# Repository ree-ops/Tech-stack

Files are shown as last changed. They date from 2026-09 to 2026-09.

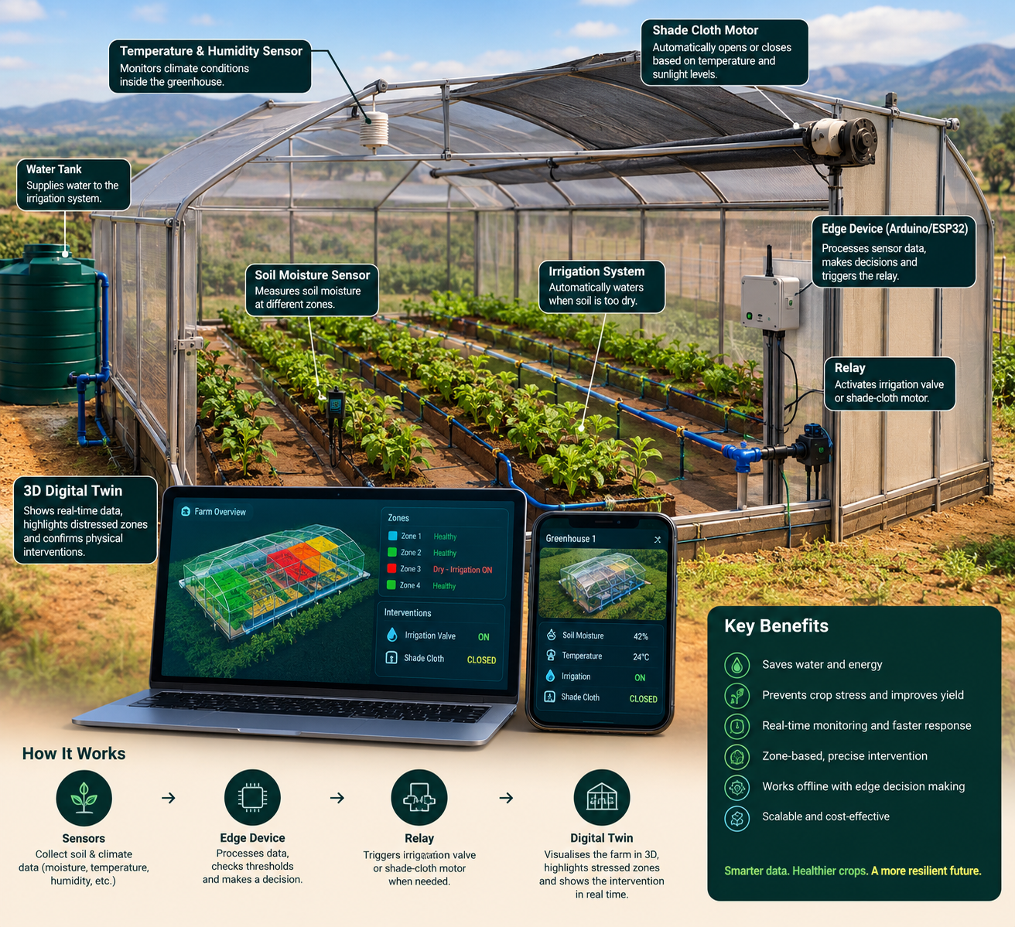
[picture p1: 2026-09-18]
EC861BFA-21BD-451A-801A-F8F32CB526BC.png

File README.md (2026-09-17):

# Lowveld Grove — Domain 2

MICTSETA Hackathon 2026, Domain 2: Smart Agribusiness & Climate Defence for
Macadamia/Citrus. A cyber-physical prototype that monitors soil moisture and
canopy temperature across several orchard sections, detects how fast each is
drying out or heating up, estimates hours until critical stress, and ranks
sections by which needs water first. When a section crosses threshold it
deploys a shade-cloth actuator and, if moisture keeps falling, switches on an
irrigation pump automatically — all shown live on a 3D digital twin. Full
detail: [docs/build-plan.md](docs/build-plan.md).

## Architecture

```
ESP32 edge node (src/edge)  --MQTT publish-->  MQTT broker
                                                    |
                                              MQTT subscribe
                                                    v
                                    mqtt-bridge (src/backend/mqtt-bridge)
                                                    |
                                          WebSocket / REST
                                          /                  \
                             dashboard (src/dashboard)   mobile (src/mobile)
                             React + Vite, 3D twin        Expo React Native
```

A simulator inside `mqtt-bridge` drives several zones with no hardware
attached — the identical dual-demo fallback path described in the build plan.
The real ESP32 rig (zone `04` / West block) can run alongside the simulated
zones, so the demo always has multiple sections to prioritize between even
with one physical rig.

`mqtt-bridge` enriches raw telemetry with a predictive layer before
broadcasting it: drying/warming rate, hours until critical stress, a
`stress_code` (`OK`/`WATCH`/`WARNING`/`CRITICAL`), and a `priority_rank`
across zones. See [src/backend/mqtt-bridge/README.md](src/backend/mqtt-bridge/README.md)
for the full zone status shape and the thresholds behind it.

```json
{
  "zone_id": "04",
  "label": "West block",
  "soil_moisture": 27.4,
  "canopy_temp": 29.1,
  "actuator_on": true,
  "pump_on": false,
  "moisture_rate_pct_per_hr": -3.2,
  "temp_rate_c_per_hr": 0.8,
  "hours_to_critical": 4.5,
  "stress_code": "WARNING",
  "priority_rank": 1,
  "ts": 1737024000000
}
```

## Repo layout

```
lowveld-grove/
  src/
    edge/                  # ESP32 firmware (Arduino, hand-written by the team)
    backend/mqtt-bridge/   # Node.js/TypeScript MQTT-to-WebSocket bridge + simulator
    dashboard/             # React (Vite) web app — 3D digital twin, chart, controls
    mobile/                # React Native (Expo) companion app
  cad/                     # optional enclosure/mounting designs
  slides/                  # pitch deck
  media/                   # team + build-progress photos
  docs/build-plan.md       # full build plan
```

## Setup

Requires Node.js 18+ and npm. Each project has its own `package.json`; there is
no shared workspace root, so `npm install` in each directory separately:

```bash
# 1. Backend (MQTT bridge + simulator)
cd src/backend/mqtt-bridge
cp .env.example .env
npm install
npm run dev            # http://localhost:8080, ws://localhost:8080/ws

# 2. Web dashboard
cd src/dashboard
cp .env.example .env
npm install
npm run dev            # http://localhost:5173

# 3. Mobile companion app
cd src/mobile
npm install
npx expo start
```

The bridge runs its own simulator by default (`SIMULATE_ON_BOOT=true`), so the
dashboard and mobile app work with no hardware attached. Once
`src/edge/farm_edge_node.ino` is flashed and publishing real MQTT data, set
`SIMULATE_ON_BOOT=false` in the bridge's `.env`.

## Demo script (the Dual-Demo)

1. **Virtual simulation** — open the dashboard, pick a section in the
   priority queue, click "Simulate heat stress" on it and watch it drift into
   stress: the stress code escalates OK → WATCH → WARNING → CRITICAL, "hours
   to critical" counts down, the shade cloth deploys and the pump switches on
   in the 3D twin, and it climbs to #1 in the priority queue. Click "Reset to
   healthy" to show recovery.
2. **Physical hardware** — show the wired ESP32/sensor/servo rig; dry the soil
   sample so the real servo moves on its own; with the simulator off, show the
   dashboard and mobile app updating that section from the real sensor.

Full script, wiring diagram, component list, and calibration steps:
[docs/build-plan.md](docs/build-plan.md).

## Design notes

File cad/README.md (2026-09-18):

# cad

3D-printable parts for the demo, written as OpenSCAD (`.scad`) source files
rather than pre-rendered STLs — free, text-based, and easy to tweak.

## Setup

1. Install [OpenSCAD](https://openscad.org/downloads.html) (free, macOS/Windows/Linux).
2. Open a `.scad` file below.
3. Press **F5** to preview, **F6** to fully render.
4. **File → Export → Export as STL**, then slice and print as usual.

These have not been test-printed — preview and check dimensions against your
actual hardware before committing filament to a print.

## Files

- **`electronics_enclosure.scad`** — a two-part project box (base + lid) for
  the Uno/ESP32 + breadboard rig, with cutouts for the USB cable and sensor
  wiring. **Measure your actual breadboard's length/width before printing**
  — the defaults at the top of the file are reasonable guesses for a
  standard full-size breadboard, not measurements of your specific setup.
  Boxing the wiring in also helps with the loose-connection issues we've
  been chasing during testing — less chance of a wire getting bumped.

- **`zone_marker_stake.scad`** — a small labeled ground stake for the demo
  table. Print 4 of these, changing `ZONE_LABEL` at the top of the file
  each time (`NORTH BLOCK`, `EAST BLOCK`, `SOUTH BLOCK`, `WEST BLOCK`) to
  match the dashboard's zone names — push one into each pot/soil tray so
  judges can see which physical section corresponds to which zone on
  screen.

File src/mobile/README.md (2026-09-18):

# mobile

Expo (React Native + TypeScript) companion app: a field-monitoring view of the
same live telemetry feed as the web dashboard, with the same "Simulate heat
stress" / "Reset to healthy" controls, priority queue, and weather widget
(temperature, humidity, rain forecast), for showing the demo from a phone.

## Setup

```bash
npm install
npm start
```

**Use `npm start` / `npm run android` / `npm run ios`, not `npx expo start`
directly** — those npm scripts auto-run `scripts/sync-lan-ip.js` first, which
detects this Mac's current WiFi IP and writes it into `app.json` for you.
Laptop IPs change often (DHCP renewals, switching networks), and a stale IP
in `app.json` is the single most common reason the app shows "CONNECTING"
forever on a physical phone. If you do run `npx expo start` directly for some
reason, run `npm run sync-lan-ip` first.

## Pointing at the backend

Phone and laptop must be on the same WiFi network as the `mqtt-bridge`
backend (`../backend/mqtt-bridge`) — the auto-sync script only fixes the IP
address in `app.json`, it can't get around the phone and laptop being on
genuinely different networks.

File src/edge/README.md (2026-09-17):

# edge

Two boards now, split by job:

- **`uno_sensor_node/`** (Arduino Uno, Arduino IDE / C++) — owns both sensors.
  Reads the soil moisture sensor and DHT22, sends raw readings to the ESP32
  over a serial link. No WiFi, no MQTT, no thresholds — just sensor reads.
- **`farm_edge_node.py`** (ESP32, **MicroPython, flashed and run via Thonny**)
  — receives those readings, converts the raw soil value to a moisture
  percentage, decides shade-cloth and irrigation-pump state locally, drives
  both, and publishes over MQTT to `lowveld-grove/zone04/telemetry` using the
  same schema the backend's simulator produces.

(The build plan in `docs/build-plan.md` describes a single-board Arduino IDE
path instead; this team split sensors onto a Uno and kept WiFi/MQTT/actuation
on the ESP32, which is why the setup below differs from that doc.)

```json
{
  "zone_id": "04",
  "soil_moisture": 27.4,
  "canopy_temp": 29.1,
  "actuator_on": true,
  "pump_on": false,
  "ts": 1737024000000
}
```

## Why two boards, and the one wiring rule that matters

The Uno's own header pins were simpler to wire the sensors into directly
than sharing breadboard rails across everything. The tradeoff: the two
boards now need a serial link between them, and their logic levels don't
match — the Uno runs 5V logic, the ESP32's pins are 3.3V-only and can be
damaged by 5V.

**Uno → ESP32 (the direction that needs protection):**
```
Uno D3 (TX) ──[1kΩ]──●──[2kΩ]──── GND
                      │
                ESP32 GPIO25 (RX)
```
That divider drops 5V to ~3.3V. Don't skip it.

**ESP32 → Uno (the safe direction, no divider needed):**
```
ESP32 GPIO26 (TX) ──────────────── Uno D2 (RX)
```
3.3V is still read as a clear HIGH by the Uno's 5V-logic input, so this one
just needs a direct wire.

**Plus a shared ground:**
```
ESP32 GND ──────────────────────── Uno GND
```

GPIO25/26 (not the more common 16/17) on purpose — those double as PSRAM
lines on WROVER-variant ESP32 boards, so 25/26 sidesteps that conflict
regardless of which variant you have.

## Setup — Uno (Arduino IDE)

1. Install the **DHT sensor library** (Adafruit) and **Adafruit Unified
   Sensor** via Library Manager.
2. Wire the soil sensor to A0 and the DHT22 to D4, both powered from the
   Uno's own 5V/GND pins — no breadboard rail-sharing needed, everything
   plugs straight into the Uno's header.
3. Wire the serial link and divider to the ESP32 as above.
4. Open `uno_sensor_node/uno_sensor_node.ino`, upload it, then open the
   Serial Monitor (9600 baud) to confirm it prints `-> ESP32: soil_raw=...
   temp=...` every 2 seconds. Note the raw value dry, then in a cup of
   water — you'll need both for calibration.

## Setup — ESP32 (Thonny)

1. Flash MicroPython onto the ESP32 if you haven't already (Thonny:
   **Tools → Options → Interpreter → Install or update firmware**), then
   confirm the bottom-right of Thonny shows `MicroPython (ESP32)` connected
   over USB serial.
2. Wire the servo signal to GPIO13 and the pump relay's signal pin to
   GPIO27 (the relay/MOSFET module switches the pump itself — a GPIO pin
   can't drive a pump's current directly).
3. Install the MQTT client library (needs WiFi connected first):

   ```python
   import network
   wlan = network.WLAN(network.STA_IF)
   wlan.active(True)
   wlan.connect("YOUR_SSID", "YOUR_PASSWORD")
   # wait until wlan.isconnected() is True, then:
   import mip
   mip.install("umqtt.simple")
   ```

   Or via Thonny's menu: **Tools → Manage Packages** → search
   `umqtt.simple` → install.
4. Open `farm_edge_node.py`, fill in `WIFI_SSID` / `WIFI_PASSWORD`, and set
   `SOIL_DRY_RAW` / `SOIL_WET_RAW` from the raw values you noted on the
   Uno's Serial Monitor in step 4 above. Check the threshold constants
   match the backend's `.env` (`src/backend/mqtt-bridge/.env.example`).
5. Save it onto the device as `main.py` (Thonny: **File → Save As...** →
   pick the MicroPython device → filename `main.py`) so it runs
   automatically on power-up for an untethered demo. Running it via the
   editor's ▶ button first (as `<untitled>` / any other filename) is fine
   for testing — it just won't survive a reboot until it's saved as
   `main.py`.

## Testing against the software stack

With both boards powered and wired together, and `src/backend/mqtt-bridge`
running (`npm run dev`), watch the Thonny Shell for `[MQTT] {...}` print
lines, then open the dashboard (`http://localhost:5173`) — zone `04` ("West
block") should switch from the backend's simulator to these real readings
automatically; the other three zones stay simulator-driven so the priority
queue still has multiple sections to compare.

If the ESP32 keeps printing "No (recent) data from Uno yet": check the Uno's
own Serial Monitor is still printing lines (confirms the Uno side is fine),
then check the divider and the TX/RX wires aren't swapped — the single most
common mistake here is connecting TX to TX instead of TX to RX.

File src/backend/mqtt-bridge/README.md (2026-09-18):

# mqtt-bridge

Subscribes to the farm telemetry MQTT topic and forwards zone status to the
dashboard (web) and mobile app over a shared WebSocket feed. Also runs a
fallback simulator across several zones so the dashboard works with no
hardware attached, and exposes the "Simulate heat stress event" / "Reset to
healthy" REST triggers used by both frontends.

On top of raw telemetry, every zone is run through a predictive layer
(`src/prediction.ts`) that:

- **detects drying/warming rate** — soil moisture %/hr and canopy temp °C/hr,
  from a rolling trend window (`TREND_WINDOW_MS`, default 10 min; needs at
  least 3 min of history before it trusts a slope, and ignores swings smaller
  than the sensor-noise deadband — see the comments in `prediction.ts`)
- **estimates hours until critical stress** (`hours_to_critical`) by
  projecting that rate forward to `CRITICAL_MOISTURE` / `CRITICAL_TEMP`
- **assigns a predictive stress code** — `OK` / `WATCH` / `WARNING` / `CRITICAL`
- **ranks zones by urgency** (`priority_rank`) — soonest-to-critical first,
  answering "which side needs water first"

The irrigation pump (`pump_on`) switches on automatically once soil moisture
drops to `PUMP_MOISTURE_THRESHOLD`, independently of the shade-cloth actuator
(`actuator_on`, driven by `MOISTURE_THRESHOLD` / `CRITICAL_TEMP`).

`src/weather.ts` polls OpenWeatherMap every `WEATHER_POLL_INTERVAL_MS` (needs
`OPENWEATHER_API_KEY` set) for the coordinates in `WEATHER_LAT`/`WEATHER_LON`,
and broadcasts it to clients. If rain is expected in the next ~9 hours,
simulated zones defer switching the pump on (no point irrigating right before
the sky does it for free) — the shade cloth still responds to heat/dryness
regardless. Real hardware zones aren't affected by this: they decide locally
on-device, per the no-cloud-dependency design; the weather check only
applies to the simulated fallback.

**Humidity feeds the "hours to critical" projection directly**, for every
zone (real or simulated) — this one *is* a backend analytics adjustment, not
an actuation decision, so it applies uniformly. Low ambient humidity means
faster evaporation than the sensor trend alone would suggest, so
`getHumidityDryingMultiplier()` in `weather.ts` scales the moisture-based
projection: >1 shortens the estimate (drying faster than the raw trend
implies), <1 lengthens it, with 50% humidity as the neutral baseline. It's a
simple, explainable multiplier, not a full evapotranspiration model — good
enough for "does this need water in the next hour or the next day," not
agronomic precision.

## Setup

```bash
cp .env.example .env
npm install
npm run dev
```

Server listens on `http://localhost:8080`, with the live feed at
`ws://localhost:8080/ws`.

## Endpoints

- `GET /api/zones` — every zone's current status, prediction, and priority rank
- `GET /api/weather` — latest weather snapshot (`{ weather: WeatherSnapshot | null }`)
- `POST /api/simulate/heat-stress` — `{ "zone_id": "03" }` drives that simulated zone into a stress event (omit `zone_id` to affect all simulated zones)
- `POST /api/simulate/reset` — same shape, returns a zone (or all) to healthy
- `ws://.../ws` — pushes `{ type: 'zones', payload: ZoneStatus[] }`, `{ type: 'event', payload }`, and `{ type: 'weather', payload: WeatherSnapshot }` messages

## Zone status shape

```json
{
  "zone_id": "04",
  "label": "West block",
  "soil_moisture": 27.4,
  "canopy_temp": 29.1,
  "actuator_on": true,
  "pump_on": false,
  "moisture_rate_pct_per_hr": -3.2,
  "temp_rate_c_per_hr": 0.8,
  "hours_to_critical": 4.5,
  "stress_code": "WARNING",
  "priority_rank": 1,
  "ts": 1737024000000
}
```

The MQTT wire schema from the ESP32 (`src/edge/farm_edge_node.ino`) only needs
`zone_id`, `soil_moisture`, `canopy_temp`, `actuator_on`, `ts` — `pump_on` is
optional on the wire and defaults from `PUMP_MOISTURE_THRESHOLD` if the
firmware doesn't send it yet. Everything else (`label`, the rate/prediction
fields, `priority_rank`) is computed by this bridge, not by the device.

Set `SIMULATE_ON_BOOT=false` in `.env` once the real ESP32 edge node is
publishing to the MQTT topic — its zone (`04` / West block by default, see
`src/zones.ts`) will then be driven by real sensor data while the rest stay
simulated, which is useful for a demo with only one physical rig.

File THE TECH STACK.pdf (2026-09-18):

# DOMAIN 2 : SMART AGRIBUSINESS &

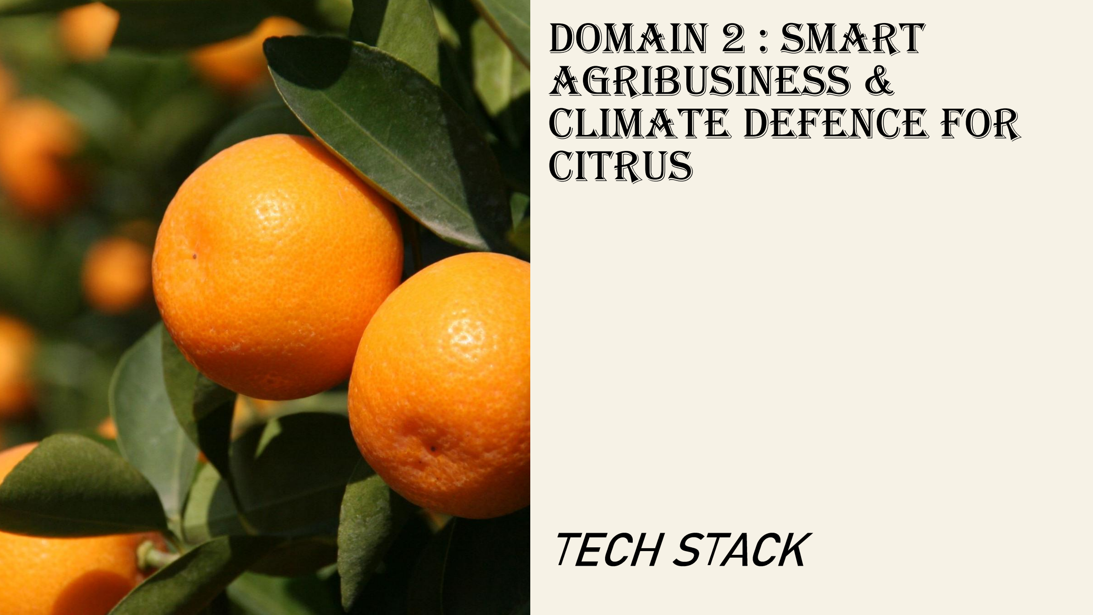
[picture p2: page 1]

# CLIMATE DEFENCE FOR CITRUS

# TECH STACK

# INTRODUCTION

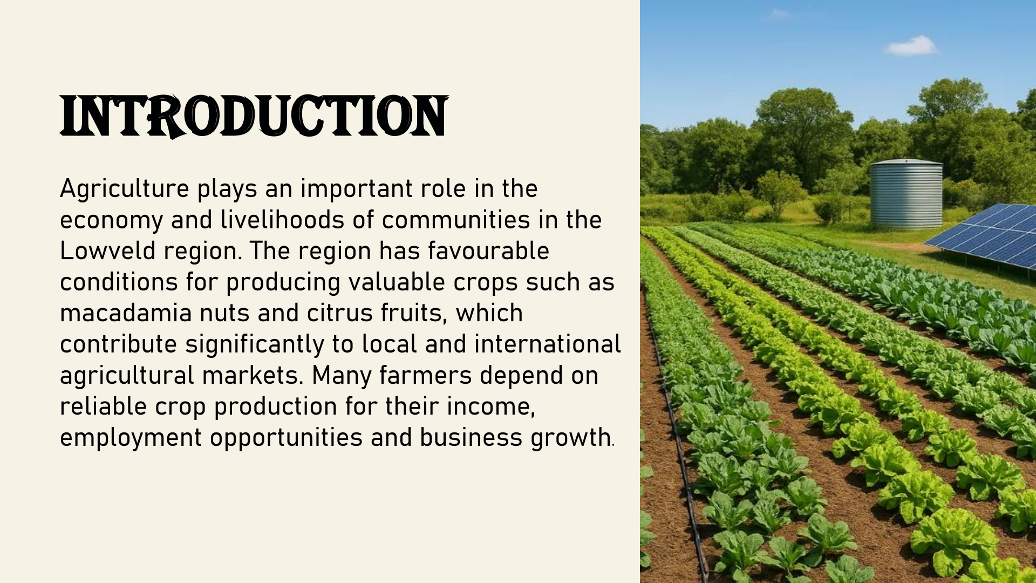
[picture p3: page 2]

Agriculture plays an important role in the economy and livelihoods of communities in the Lowveld region. The region has favourable conditions for producing valuable crops such as macadamia nuts and citrus fruits, which contribute significantly to local and international agricultural markets. Many farmers depend on

reliable crop production for their income, employment opportunities and business growth .

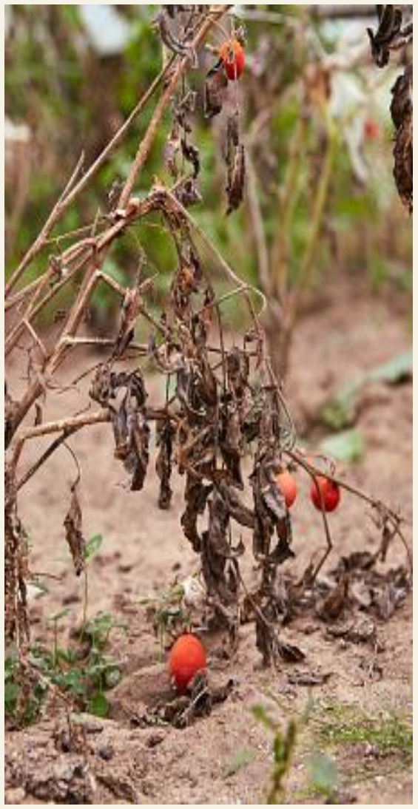
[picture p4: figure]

# PROBLEM STATEMENT

However :

- climate variability is creating challenges for farmers because conditions such as soil moisture and temperature can change significantly .
- One major problem is insufficient soil moisture. When there is not enough water in the soil, crops can experience water stress, which can negatively affect their growth and production. On the other hand, excessive irrigation can waste valuable water and increase
- Another problem is high temperatures. Extreme heat can cause stress to plants and may affect crop development and quality. Farmers therefore need to know when and where conditions are becoming dangerous so that they can take action quick
- It can be difficult and time - consuming to manually check every area. Problems may only be noticed after the crops have already been affected. This creates a need for a system that
can continuously monitor environmental conditions and identify stressed areas

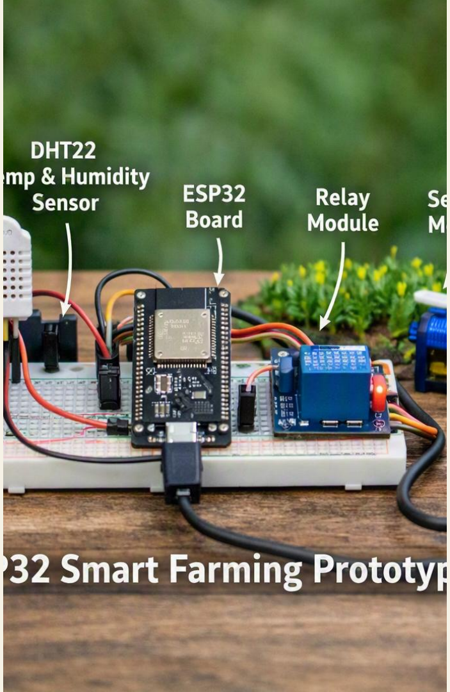
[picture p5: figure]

# SOLUTION :

### - The proposed solution is a smart agricultural monitoring and climate defence system that uses environmental sensors to

monitor conditions in macadamia and citrus farms | .
- Senses soil moisture and temperature | .
- A wind speed that will detect strong wind that | can damage cr ops.
- Buzzer that will give alert severe crops stress | .
- WIFI will allow the 3D digital twin to receive live data.

### - The device will detect how fast the soil is drying and how fast the

### - Estimate hours until the critical stress to the plant(Predictive

- Prioritise sections to know which sides to get water first.

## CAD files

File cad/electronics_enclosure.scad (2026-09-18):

// Lowveld Grove — Electronics enclosure (base + lid)
//
// A project box for the Uno/ESP32 + breadboard rig. The whole point is to
// stop wires from being disturbed by hand contact — which has been the
// single biggest source of the flaky/intermittent sensor readings during
// testing. Boxing the wiring in reduces exactly that risk.
//
// IMPORTANT: measure your actual breadboard/board footprint before
// printing — the numbers below are reasonable guesses for a standard
// full-size breadboard, not measurements of your specific hardware. Open
// this in OpenSCAD (openscad.org, free), adjust the parameters, preview
// with F5, render with F6, then File > Export > Export as STL.
//
// Prints as two separate parts (base and lid) laid out side by side —
// slice and print both.

// ---- Parameters (mm) — measure and adjust these ----
board_length = 170;      // breadboard length
board_width  = 65;       // breadboard width
board_height = 12;       // clearance above the board for the tallest component (e.g. the servo horn or relay)
wall = 2.4;              // wall thickness — 2-2.5mm is a good default for most printers
lid_lip = 1.4;           // how far the lid's inner lip overlaps the base wall (fit tolerance)
usb_notch_width = 14;
usb_notch_height = 9;
wire_notch_width = 24;
wire_notch_height = 7;
corner_radius = 4;

base_height = board_height + 6; // extra clearance for wires routed underneath/beside the board

module rounded_box(l, w, h, r) {
  hull() {
    for (x = [r, l - r])
      for (y = [r, w - r])
        translate([x, y, 0])
          cylinder(h = h, r = r, $fn = 32);
  }
}

module base() {
  difference() {
    rounded_box(board_length + 2 * wall, board_width + 2 * wall, base_height, corner_radius);

    // hollow interior
    translate([wall, wall, wall])
      rounded_box(board_length, board_width, base_height, corner_radius - 1);

    // USB cable notch — one side wall, for programming/power without opening the box
    translate([-1, board_width / 2 - usb_notch_width / 2 + wall, wall])
      cube([wall + 2, usb_notch_width, usb_notch_height]);

    // Sensor/servo/relay wire notch — opposite side wall
    translate([board_length + wall - 1, board_width / 2 - wire_notch_width / 2 + wall, wall])
      cube([wall + 2, wire_notch_width, wire_notch_height]);
  }
}

module lid() {
  lid_height = 4;
  difference() {
    rounded_box(board_length + 2 * wall, board_width + 2 * wall, lid_height, corner_radius);
    translate([wall - lid_lip, wall - lid_lip, -1])
      rounded_box(
        board_length + 2 * lid_lip,
        board_width + 2 * lid_lip,
        lid_height - 1.5,
        corner_radius - 1
      );
  }
}

base();
translate([0, board_width + 2 * wall + 12, 0]) lid();

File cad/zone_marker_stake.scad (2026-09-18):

// Lowveld Grove — Zone marker stake
//
// A small labeled ground stake for the demo table — push one into each of
// the four pots/soil trays so judges can see "North block", "East block",
// etc. matching the dashboard's zone names at a glance.
//
// Print 4x total: change ZONE_LABEL below, re-render (F6), export STL,
// print, then repeat for the other three zone names.

ZONE_LABEL = "WEST BLOCK";  // change to NORTH BLOCK / EAST BLOCK / SOUTH BLOCK / WEST BLOCK per print

stake_width = 6;     // stake cross-section at its base (mm)
stake_length = 70;   // how far it goes into the soil (mm)
flag_width = 44;
flag_height = 26;
flag_thickness = 3;
text_size = 6.5;

// Tapered stake — square cross-section at the base, narrowing toward the tip.
module stake() {
  linear_extrude(height = stake_length, scale = 0.08)
    square([stake_width, stake_width], center = true);
}

// Flag sits on top of the stake, with the zone name embossed (cut) through it.
module flag() {
  translate([0, 0, stake_length]) {
    difference() {
      translate([-flag_width / 2, -flag_thickness / 2, 0])
        cube([flag_width, flag_thickness, flag_height]);

      translate([0, 0, flag_height / 2])
        rotate([90, 0, 0])
          linear_extrude(height = flag_thickness + 2, center = true)
            text(
              ZONE_LABEL,
              size = text_size,
              halign = "center",
              valign = "center",
              font = "Liberation Sans:style=Bold"
            );
    }
  }
}

stake();
flag();

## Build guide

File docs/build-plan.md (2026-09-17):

# Lowveld Grove — Domain 2 Build Plan

2026-09-17

## Project overview

Lowveld Grove is a cyber-physical prototype for MICTSETA Hackathon 2026, Domain 2:
Smart Agribusiness & Climate Defence for Macadamia/Citrus. It monitors soil moisture
and canopy temperature in a simulated orchard zone, and when a stress threshold is
breached, an edge device automatically deploys a shade-cloth actuator while a live 3D
digital twin shows the zone's state changing in real time.

**Why this domain:** low hardware risk (soil/temp sensors are cheap and reliable), a
self-explanatory threshold-based system with no gap between what's claimed and what's
built, and a strong, easy-to-pitch Mpumalanga story (Lowveld macadamia/citrus exports).

**Winning strategy against the rubric:**

| Rubric criterion | Weight | How this build addresses it |
| --- | --- | --- |
| Dual-Demo Execution | 25% | Software simulation and physical rig run on the identical MQTT schema, so either can drive the demo; simulation is the scored fallback if hardware fails live |
| Systems Integration & Physical Actuation | 20% | Real sensor -> ESP32 edge logic -> real servo, with the decision made locally (no cloud dependency) |
| Spatial Visualization & 3D Twinning | 20% | Farm-zone grid twin recolors live per zone and shows actuator state, not a static scene |
| Problem Relevance & Mpumalanga Impact | 20% | Macadamia/citrus exports are a major, credible Lowveld economic driver |
| Pitch Presentation | 15% | Clear before/after demo narrative: stress detected, actuator responds, twin confirms it |

## Component list

A relay module is intentionally left out: the SG90 draws little enough current to run
straight off the ESP32's 5V pin for demo purposes, which removes one potential point of
failure.

| Part | Spec | Qty | Purpose | SA sourcing | Approx. price |
| --- | --- | --- | --- | --- | --- |
| ESP32 dev board | ESP32-WROOM-32 DevKit | 1 | Edge compute, WiFi, MQTT publish | RS Components, Communica, Mantech Electronics, Takealot | R120-180 |
| Capacitive soil moisture sensor | v1.2, analog output | 1 | Soil moisture reading (corrosion-resistant, unlike resistive probes) | Same suppliers | R40-80 |
| DHT22 (AM2302) | Digital temp/humidity sensor | 1 | Canopy temperature reading | Same suppliers | R80-120 |
| SG90 micro servo | 180deg, 5V | 1 | Shade-cloth flap actuator | Any hobby/electronics supplier | R40-60 |
| Breadboard + jumper wires | Standard prototyping kit | 1 set | Wiring | Any electronics kit | R60-100 |
| USB cable / power bank | 5V micro-USB or USB-C depending on board | 1 | Power the ESP32 untethered on demo day | Already on hand | - |
| Small potted plant or soil tray | Any small pot with soil | 1 | Physical "farm zone" prop for the demo | Home/garden | - |

## Wiring and pin mapping

```
ESP32["ESP32 DevKit"]
SOIL["Soil moisture sensor"]
DHT["DHT22"]
SERVO["SG90 servo"]

SOIL -->|AOUT to GPIO34| ESP32
SOIL -->|VCC to 3V3, GND to GND| ESP32
DHT -->|DATA to GPIO4| ESP32
DHT -->|VCC to 3V3, GND to GND| ESP32
ESP32 -->|PWM signal GPIO13| SERVO
ESP32 -->|5V and GND| SERVO
```

Keep the soil sensor's exposed prongs out of standing water and only in moist soil, to
avoid long-term corrosion even though it is capacitive.

| ESP32 pin | Connects to | Notes |
| --- | --- | --- |
| GPIO34 (ADC1) | Soil sensor AOUT | Analog-only pin, cannot be used as output |
| 3V3 | Soil sensor VCC, DHT22 VCC | Shared 3.3V rail |
| GND | Soil sensor GND, DHT22 GND, servo GND | Common ground for all components |
| GPIO4 | DHT22 DATA | Add a 10k ohm pull-up resistor between DATA and 3V3 if readings are unstable |
| GPIO13 | Servo signal (orange/yellow wire) | PWM output |
| 5V (VIN) | Servo VCC (red wire) | Servo draws more current than a 3.3V pin can safely supply |

## Software architecture

```
A["ESP32 edge node: reads sensors, applies threshold"] -->|MQTT publish| B["MQTT broker: e.g. HiveMQ public or local Mosquitto"]
B -->|MQTT subscribe| C["Backend bridge: Node.js/Python"]
C -->|WebSocket or REST| D["3D digital twin dashboard: farm-twin.html"]
E["Simulated data generator: same JSON schema"] -.->|fallback path| B
```

**Shared MQTT schema** (used by both the real ESP32 and the software simulator, so
either can drive the dashboard without changing it):

```json
{
  "zone_id": "04",
  "soil_moisture": 27.4,
  "canopy_temp": 29.1,
  "actuator_on": true,
  "ts": 1737024000000
}
```

**Components already built (this repo):**

- `src/backend/mqtt-bridge` — Node.js/TypeScript backend: subscribes to the MQTT
  topic, runs a fallback simulator across several zones, and forwards enriched
  state to clients over WebSocket.
- `src/dashboard` — React + Vite web app: live 3D digital twin, priority queue,
  telemetry chart, and Dual-Demo controls.
- `src/mobile` — Expo (React Native) companion app: same live feed, priority
  queue, and controls, for demoing from a phone.

**Still to build (by the team, in the Arduino IDE):**

- `src/edge/farm_edge_node.ino` — ESP32 firmware. See setup instructions below.

### Predictive stress & auto-irrigation (added after the original plan)

`mqtt-bridge` doesn't just relay the raw MQTT reading — for every zone it also:

- **detects the drying/warming rate** (soil moisture %/hr, canopy temp °C/hr)
  from a rolling trend window, once enough history has built up to tell a
  real trend from sensor jitter
- **estimates hours until critical stress** by projecting that rate forward
  to a critical moisture/temperature level
- **assigns a predictive stress code** — `OK` → `WATCH` → `WARNING` → `CRITICAL`
- **ranks every zone by urgency** (soonest-to-critical first) — this is the
  priority queue in the dashboard and mobile app, answering "which side needs
  water first"
- **switches the irrigation pump on automatically** once moisture drops to a
  lower, more urgent threshold than the one that deploys the shade cloth

This is why the software stack simulates four zones (North/East/South/West
block) instead of one: prioritizing between sections only means something
with more than one section to compare. The real ESP32 rig still only wires up
one physical zone (`04` / West block); the rest stay simulator-driven so the
demo always has a full priority queue to show. Full detail, thresholds, and
the zone status JSON shape: [src/backend/mqtt-bridge/README.md](../src/backend/mqtt-bridge/README.md).

## Setup instructions, from scratch

**Note:** this team ended up flashing the ESP32 with **MicroPython and using
Thonny** instead of the Arduino IDE / C++ path below, and later split the
sensors onto a separate **Arduino Uno** (reading soil moisture + DHT22,
handed to the ESP32 over a serial link) once wiring everything onto one
board got unwieldy. If that's your setup, skip to
[src/edge/README.md](../src/edge/README.md) instead — the pin mapping and
calibration steps below still apply to whichever board actually has the
sensors wired to it.

### 1. Arduino IDE setup

1. Install the Arduino IDE (2.x).
2. File > Preferences > add this URL to "Additional boards manager URLs":
   `https://raw.githubusercontent.com/espressif/arduino-esp32/gh-pages/package_esp32_index.json`
3. Tools > Board > Boards Manager > search "esp32" > install the Espressif package.
4. Tools > Board > select your ESP32 DevKit variant.
5. Library Manager: install `DHT sensor library` (Adafruit), `Adafruit Unified Sensor`,
   `PubSubClient`, `ESP32Servo`.

### 2. Wire the hardware per the pin mapping above.

### 3. Flash the firmware

1. Open `farm_edge_node.ino`.
2. Set `WIFI_SSID` and `WIFI_PASSWORD` to your hotspot or venue WiFi.
3. Leave `MQTT_BROKER` as `broker.hivemq.com` for a quick start, or point it at your
   own Mosquitto instance.
4. Select the correct COM/USB port under Tools > Port.
5. Upload. Open the Serial Monitor at 115200 baud to confirm readings are printing.

### 4. Run the software stack

1. `src/backend/mqtt-bridge`: `cp .env.example .env && npm install && npm run dev`
2. `src/dashboard`: `cp .env.example .env && npm install && npm run dev`, open
   `http://localhost:5173`.
3. `src/mobile`: `npm install && npx expo start` (see its README for pointing at a
   physical phone).

### 5. Test end-to-end

1. With the ESP32 powered and connected, watch the Serial Monitor for `[MQTT]` log
   lines.
2. Use an MQTT client (e.g. MQTT Explorer, or `mosquitto_sub`) to confirm messages
   are arriving on the topic `lowveld-grove/zone04/telemetry`.
3. Confirm the dashboard and mobile app update from real sensor values instead of
   the bridge's built-in simulator (set `SIMULATE_ON_BOOT=false` in the bridge's
   `.env` once the ESP32 is live).

## Calibration and threshold tuning

The capacitive soil sensor outputs a raw analog value (0-4095 on the ESP32's ADC)
that must be mapped to a 0-100% moisture range before the threshold logic means
anything.

1. Upload the firmware and open the Serial Monitor.
2. Hold the sensor in dry air (not touching anything) and note the raw
   `analogRead()` value — this is `SOIL_DRY_RAW`.
3. Submerge the sensor's prongs in a cup of water and note the raw value — this is
   `SOIL_WET_RAW`.
4. Update these two constants at the top of `farm_edge_node.ino` with your measured
   values (the firmware ships with placeholder estimates of 2800 dry / 1200 wet,
   which will likely need adjusting per individual sensor unit).
5. Re-upload and confirm the Serial Monitor now reports sensible percentages in dry
   soil versus wet soil.

**Threshold:** `MOISTURE_THRESHOLD` is set to 28%, matching the dashboard's and
bridge's default threshold and the dashed line on its chart. If the calibration
makes 28% impractical to reach on stage within demo time, lower the threshold
(e.g. to 35-40%) so a normal watering demonstration crosses it quickly — just
update the same value in the firmware and in `MOISTURE_THRESHOLD` /
`VITE_MOISTURE_THRESHOLD` / `app.json`'s `moistureThreshold` so they stay in sync.

## Demo script (the Dual-Demo)

### Part 1 - Virtual simulation (proves the telemetry logic)

1. Open the dashboard (`src/dashboard`, `npm run dev`) on the projector/screen.
2. Narrate the schema and edge-decision logic while the baseline healthy state is
   visible.
3. Click "Simulate heat stress event." Narrate as Zone 04 drifts amber, then red,
   the chart crosses the dashed threshold, the shade cloth deploys in the 3D twin,
   and the event log fires.
4. Click "Reset to healthy" to show recovery and the actuator retracting.

### Part 2 - Physical hardware prototype (proves mechanical actuation)

1. Show the wired ESP32, sensor, and servo rig.
2. Physically dry the soil sample slightly, or wait for it to be below the
   calibrated threshold, so the audience sees the real servo move without you
   touching it.
3. Point out the Serial Monitor or an MQTT client showing the live message stream,
   and — with the bridge's `SIMULATE_ON_BOOT` turned off — show the twin (and the
   mobile app) updating from the real sensor in real time.

**Fallback framing:** state explicitly to the judges that the virtual simulation
runs on the identical schema and threshold logic as the physical rig, so if
anything about the hardware misbehaves live, the simulation is a faithful
stand-in, not a separate demo. This directly answers the rubric's language on
evaluating "how effectively the simulation serves as a fallback if physical
hardware fails."

## GitHub repository structure

Matches the mandatory deliverable requirements exactly, since the brief states
missing elements lead to immediate disqualification.

```
lowveld-grove/
  README.md
  src/
    edge/
      farm_edge_node.ino
    backend/
      mqtt-bridge/        # subscribes to MQTT, forwards to dashboard + mobile
    dashboard/             # React (Vite) web app — 3D digital twin
    mobile/                # React Native (Expo) companion app
  cad/                     # optional: enclosure or mounting designs, if any
  slides/
    lowveld-grove-pitch.pdf
  media/
    team/                  # clear photos of each team member
    build-progress/        # dated photos taken throughout the build, not staged at the end
  docs/
    build-plan.md          # this document
```

`README.md` should cover: problem statement, architecture summary (the diagram
from Software architecture, above), setup instructions (link to or restate Setup
instructions), and the demo script. GitHub username on record: MRNMT.

## Build timeline

### Boot Camp (before Checkpoint 2 - virtual simulation must be mentor-approved before touching hardware)

- [ ] Finalize the MQTT schema and interface contract
- [ ] Confirm the dashboard fully demonstrates the threshold and actuator logic on simulated data
- [ ] Order/source all physical components
- [ ] Draft the README and repo skeleton
- [ ] Present the virtual data flow and interface contract at Checkpoint 2

### Hackathon Sprint, Day 1 (after Checkpoint 2 approval)

- [ ] Wire the ESP32, soil sensor, DHT22, and servo
- [ ] Flash and calibrate the firmware (see Calibration section)
- [ ] Confirm MQTT messages are publishing correctly
- [ ] Build the backend bridge connecting MQTT to the dashboard
- [ ] Confirm the dashboard updates from live sensor data

### Hackathon Sprint, Day 2 / Night

- [ ] Rehearse the full Dual-Demo script end-to-end at least twice
- [ ] Take and organize team and build-progress photos for the media folder
- [ ] Finalize the slide deck (problem statement, methodology, commercialisation pathway, Mpumalanga impact)
- [ ] Push final source code, CAD (if any), slides, and media to the public GitHub repo
- [ ] Audit the repo against the mandatory deliverables list before submission

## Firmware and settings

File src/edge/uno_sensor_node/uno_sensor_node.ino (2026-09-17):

/*
 * Lowveld Grove — Arduino Uno sensor node
 *
 * Reads the soil moisture sensor and DHT22 and sends them to the ESP32
 * over a SoftwareSerial link as a plain CSV line:
 *
 *   <soil_raw_0_to_1023>,<canopy_temp_c>\n
 *
 * The Uno does no threshold logic and no MQTT — it only reads sensors.
 * The ESP32 (farm_edge_node.py) converts the raw value to a moisture
 * percentage, makes the shade/pump decisions, and publishes over MQTT.
 *
 * Wiring:
 *   Soil sensor AOUT -> A0, VCC -> 5V, GND -> GND
 *   DHT22 DATA        -> D4,  VCC -> 5V, GND -> GND
 *   D2 (RX)  <- ESP32 GPIO26 (TX)                — direct, no divider needed
 *   D3 (TX)  -> [1k/2k divider] -> ESP32 GPIO25 (RX) — REQUIRED, do not skip
 *   GND      -> ESP32 GND
 *
 * Needs the "DHT sensor library" (Adafruit) + "Adafruit Unified Sensor"
 * installed via the Arduino IDE Library Manager.
 */

#include <SoftwareSerial.h>
#include <DHT.h>

#define SOIL_PIN A0
#define DHT_PIN 4
#define DHT_TYPE DHT22

#define ESP_RX_PIN 2  // Uno D2 <- ESP32 TX
#define ESP_TX_PIN 3  // Uno D3 -> divider -> ESP32 RX

#define PUBLISH_INTERVAL_MS 2000

SoftwareSerial espSerial(ESP_RX_PIN, ESP_TX_PIN);
DHT dht(DHT_PIN, DHT_TYPE);

void setup() {
  Serial.begin(9600);     // USB serial monitor, for local debugging only
  espSerial.begin(9600);  // link to the ESP32
  dht.begin();
  Serial.println("Uno sensor node ready");
}

void loop() {
  int soilRaw = analogRead(SOIL_PIN);
  float tempC = dht.readTemperature();

  if (isnan(tempC)) {
    Serial.println("DHT22 read failed, skipping this cycle");
    delay(PUBLISH_INTERVAL_MS);
    return;
  }

  espSerial.print(soilRaw);
  espSerial.print(",");
  espSerial.println(tempC, 1);

  Serial.print("-> ESP32: soil_raw=");
  Serial.print(soilRaw);
  Serial.print("  temp=");
  Serial.println(tempC);

  delay(PUBLISH_INTERVAL_MS);
}

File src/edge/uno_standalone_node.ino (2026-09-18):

/*
 * Lowveld Grove — Arduino Uno standalone sensor node (USB only)
 *
 * This is what's actually running on your Uno right now, extended with the
 * DHT22 for real temperature and humidity (previously only the soil sensor
 * was read, and the bridge script filled in a fake 24C placeholder).
 *
 * No ESP32 link — this prints over USB only, read by
 * tools/uno-serial-bridge/index.js on your Mac.
 *
 * Wiring:
 *   Soil sensor AOUT -> A0, VCC -> 5V, GND -> GND
 *   DHT22 DATA        -> D4,  VCC -> 5V, GND -> GND
 *
 * Needs the "DHT sensor library" (Adafruit) + "Adafruit Unified Sensor"
 * installed via the Arduino IDE Library Manager (Sketch > Include Library >
 * Manage Libraries).
 */

#include <DHT.h>

#define SOIL_PIN A0
#define DHT_PIN 4
#define DHT_TYPE DHT22

DHT dht(DHT_PIN, DHT_TYPE);

void setup() {
  Serial.begin(9600);
  dht.begin();
}

void loop() {
  int soilValue = analogRead(SOIL_PIN);
  float tempC = dht.readTemperature();
  float humidityPct = dht.readHumidity();

  Serial.print("Soil Moisture Value: ");
  Serial.print(soilValue);

  if (isnan(tempC) || isnan(humidityPct)) {
    Serial.println("  DHT22 read failed");
  } else {
    Serial.print("  Temp: ");
    Serial.print(tempC, 1);
    Serial.print("  Humidity: ");
    Serial.println(humidityPct, 1);
  }

  delay(1000);
}

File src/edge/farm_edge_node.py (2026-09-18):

"""
Lowveld Grove — ESP32 edge node (MicroPython / Thonny)

Sensors live on a separate Arduino Uno (src/edge/uno_sensor_node), which
sends raw readings over a UART link as "<soil_raw>,<canopy_temp_c>\\n".
This board: receives those readings, converts the raw soil value to a
moisture percentage, decides shade-cloth and irrigation pump state locally
(no cloud dependency), and publishes telemetry over MQTT using the same
JSON schema the software simulator uses — so the mqtt-bridge backend and
the dashboard/mobile apps don't need to know or care whether a zone's data
is coming from real hardware or the simulator.

Wiring to the Uno (see docs/build-plan.md for the full diagram):
  ESP32 GPIO26 (TX) -> Uno D2 (RX)                      — direct, no divider
  ESP32 GPIO25 (RX) <- [1k/2k divider] <- Uno D3 (TX)    — REQUIRED, do not skip
  ESP32 GND         -- Uno GND

Before running for real:
  1. Fill in WIFI_SSID / WIFI_PASSWORD below.
  2. Calibrate SOIL_DRY_RAW / SOIL_WET_RAW (see docs/build-plan.md) — read
     them off the Uno's Serial Monitor (USB), not the ESP32's.
  3. Install umqtt.simple: `import mip; mip.install("umqtt.simple")`
     (needs WiFi connected first) or via Thonny's Tools > Manage Packages.
  4. Save this file as main.py on the device (File > Save As > MicroPython
     device) so it runs automatically on power-up, untethered.
"""

from machine import UART, Pin, PWM
import network
import ntptime
import ujson
import utime
from time import sleep

from umqtt.simple import MQTTClient

# ---- WiFi / MQTT ----
WIFI_SSID = "YOUR_WIFI_SSID"
WIFI_PASSWORD = "YOUR_WIFI_PASSWORD"

MQTT_BROKER = "broker.hivemq.com"
MQTT_TOPIC = b"lowveld-grove/zone04/telemetry"
ZONE_ID = "04"

# ---- Calibration (see docs/build-plan.md "Calibration and threshold tuning") ----
SOIL_DRY_RAW = 1023   # measured: ADC ceiling in dry air (reproduced across 2 cycles)
SOIL_WET_RAW = 472    # measured: ~470-474 in a cup of water

# ---- Thresholds — keep in sync with the backend's .env (mqtt-bridge) ----
MOISTURE_THRESHOLD = 28        # shade cloth deploys at/below this
PUMP_MOISTURE_THRESHOLD = 18   # pump switches on at/below this (more urgent)
CRITICAL_TEMP = 36             # shade cloth also deploys above this

PUBLISH_INTERVAL_S = 2
# If no line has ever arrived from the Uno within this long, stop actuating
# on stale/absent data rather than silently reusing old readings forever.
SENSOR_TIMEOUT_S = 15

# Seconds between the MicroPython epoch (2000-01-01) and the Unix epoch
# (1970-01-01), so published timestamps line up with the simulator's
# JS Date.now() (ms since 1970) instead of reading as a 1970-ish date
# in the dashboard's event log / chart.
UNIX_EPOCH_OFFSET_S = 946684800

# ---- Hardware ----
# UART2 on GPIO25/26 rather than the more common 16/17 — those double as
# PSRAM lines on WROVER boards, so 25/26 avoids that conflict either way.
uno_uart = UART(2, baudrate=9600, tx=26, rx=25)

servo = PWM(Pin(13), freq=50)
# Pump is driven through a relay/MOSFET module (unlike the servo, it draws
# far more current than a GPIO pin can source directly) — GPIO27 here is
# just the logic-level signal to that module, not the pump itself.
pump = Pin(27, Pin.OUT)

SERVO_RETRACTED_DUTY = 40   # tune for your SG90/FS90 (~0deg)
SERVO_DEPLOYED_DUTY = 115   # tune for your SG90/FS90 (~90deg)

_last_reading = None       # (soil_raw, canopy_temp) — most recent line from the Uno
_last_reading_at = None    # utime.ticks_ms() when it arrived


def connect_wifi():
    wlan = network.WLAN(network.STA_IF)
    wlan.active(True)
    if not wlan.isconnected():
        print("Connecting to WiFi...")
        wlan.connect(WIFI_SSID, WIFI_PASSWORD)
        while not wlan.isconnected():
            sleep(0.5)
    print("WiFi connected:", wlan.ifconfig())
    return wlan


def sync_clock():
    try:
        ntptime.settime()
        print("Clock synced via NTP")
    except OSError as e:
        print("NTP sync failed, timestamps will be wrong:", e)


def now_ms():
    return (utime.time() + UNIX_EPOCH_OFFSET_S) * 1000


def poll_uno():
    """Drains the UART buffer and keeps the newest well-formed reading."""
    global _last_reading, _last_reading_at

    while uno_uart.any():
        line = uno_uart.readline()
        if not line:
            break
        try:
            text = line.decode().strip()
            raw_str, temp_str = text.split(",")
            _last_reading = (int(raw_str), float(temp_str))
            _last_reading_at = utime.ticks_ms()
        except (ValueError, UnicodeError):
            print("Malformed line from Uno:", line)


def get_reading():
    """Returns (soil_moisture_pct, canopy_temp_c), or None if no fresh data."""
    if _last_reading is None:
        return None
    if utime.ticks_diff(utime.ticks_ms(), _last_reading_at) > SENSOR_TIMEOUT_S * 1000:
        return None

    soil_raw, temp = _last_reading
    pct = (SOIL_DRY_RAW - soil_raw) / (SOIL_DRY_RAW - SOIL_WET_RAW) * 100
    moisture = max(0, min(100, round(pct, 1)))
    return moisture, round(temp, 1)


def set_shade(deployed):
    servo.duty(SERVO_DEPLOYED_DUTY if deployed else SERVO_RETRACTED_DUTY)


def set_pump(on):
    pump.value(1 if on else 0)


def main():
    connect_wifi()
    sync_clock()

    client = MQTTClient("lowveld-grove-edge-04", MQTT_BROKER)
    client.connect()
    print("MQTT connected to", MQTT_BROKER)
    print("Waiting for readings from the Uno over UART2...")

    while True:
        try:
            poll_uno()
            reading = get_reading()

            if reading is None:
                print("No (recent) data from Uno yet — check the serial link and divider")
                sleep(PUBLISH_INTERVAL_S)
                continue

            moisture, temp = reading

            actuator_on = moisture <= MOISTURE_THRESHOLD or temp >= CRITICAL_TEMP
            pump_on = moisture <= PUMP_MOISTURE_THRESHOLD

            set_shade(actuator_on)
            set_pump(pump_on)

            payload = ujson.dumps({
                "zone_id": ZONE_ID,
                "soil_moisture": moisture,
                "canopy_temp": temp,
                "actuator_on": actuator_on,
                "pump_on": pump_on,
                "ts": now_ms(),
            })
            client.publish(MQTT_TOPIC, payload)
            print("[MQTT]", payload)

        except OSError as e:
            print("MQTT error:", e)

        sleep(PUBLISH_INTERVAL_S)


main()

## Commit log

2026-09-17 Initial commit: Lowveld Grove hackathon build
    React web dashboard, React Native mobile app, Node/TypeScript MQTT
    bridge with predictive stress analytics and multi-zone priority
    ranking, ESP32/Uno edge firmware, and a temporary serial-to-MQTT
    bridge tool for testing with real hardware before the ESP32 link.
2026-09-18 Add weather integration, Supabase history logging, mobile parity, and CAD parts
    - Backend: OpenWeatherMap integration (temp/humidity/rain), humidity-adjusted
    hours-to-critical projections, Supabase telemetry history logging
    - Fix predictive stress code false positives on healthy zones and across
    real/simulated data source switches
    - Dashboard: weather widget, fixed 3D twin zone ordering (was following
    priority rank instead of a stable spatial layout), chart label placement
    - Mobile: upgrade Expo SDK 51 -> 57, weather widget, per-zone trend chart
    (react-native-safe-area-context, react-native-svg), LAN IP auto-sync script
    - Add 3D-printable enclosure and zone marker stake designs (Open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
    [electronics_enclosure.scad, zone_marker_stake.scad]
2026-09-18 Add auth, real DHT22 humidity, mobile-web parity, and week-long history views
    - Backend/dashboard/mobile: email+password auth via Supabase, with local
    JWKS-based JWT verification on the WebSocket and REST API (bypasses a
    supabase-js getUser() bug that threw on an explicitly-passed token)
    - Bridge/edge: parse real temp+humidity from the DHT22-equipped Uno sketch
    instead of a placeholder temp, and surface humidity_pct on zone cards
    - Dashboard/mobile: 24h/7-day history panel reading persisted Supabase
    telemetry, with hourly bucketing beyond 48h so the chart stays readable
    - Mobile: sign-in, Supabase read of long-term zone history, signed-in-user
    display, SDK 57 upgrade
    - Fix zone_tel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
    [uno_standalone_node.ino]
